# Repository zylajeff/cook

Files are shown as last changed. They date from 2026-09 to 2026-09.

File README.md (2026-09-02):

# Cook — Block-M Seeker

A Jetson Nano application that watches a Raspberry Pi camera feed for a
University of Michigan Block M, renders a missile-seeker HUD on the attached
display, and fires a pneumatic Nerf dart through a 12V solenoid — but only while
a physical toggle switch is held in the armed position.

```
camera ──▶ detector ──▶ tracker ──▶ interlocks ──▶ relay ──▶ solenoid
              │             │            │
              └─────────────┴────────────┴──────▶ seeker HUD ──▶ display
```

## Quick start

On a workstation with no hardware attached, everything runs against a synthetic
feed:

```bash
python -m pip install -e ".[dev]"
cook-vision --source synthetic --gpio mock --windowed
```

Press `a` to simulate flipping the arm switch, `f` to fire manually, `m` to see
the raw colour mask, `q` to quit.

On the Jetson:

```bash
python -m pip install -e ".[jetson]"     # NOT [dev]: keep the stock OpenCV
cook-vision
```

The camera source, GPIO backend, and display mode all default to `auto`, so the
bare command picks the CSI camera, real GPIO, and a fullscreen window.

## Safety

Firing is gated by eight interlocks, evaluated every frame and drawn along the
bottom of the HUD. All eight must pass:

| Interlock | Meaning |
|---|---|
| `startup` | 3s power-on lockout has elapsed |
| `arm switch` | the physical toggle is closed |
| `software safe` | the on-screen safety (`s`) is off |
| `target lock` | a track has persisted for 8 consecutive frames |
| `confidence` | the locked target scores ≥ 0.60 |
| `on bore` | the target is within 10% of frame width of the reticle |
| `cooldown` | ≥ 1.5s since the last shot |
| `relay idle` | the coil is not currently energised |

Three further protections are not interlocks but always apply:

- The relay pin is initialised to its **inactive** level, so bringing GPIO up
  cannot fire a dart.
- Every energise arms a watchdog timer that releases the coil after
  `max_pulse_seconds` (0.5s) even if the main loop stalls or crashes. A 12V
  solenoid held on will cook its coil.
- `atexit` and the shutdown path both de-energise the relay.

The launcher is fixed forward in this build — there is no pan/tilt yet — so the
`on bore` gate exists because a target the seeker can *see* is not necessarily a
target the barrel is *pointed at*.

## Detection

Two interchangeable backends behind one interface:

- **`color`** (default) — isolates the maize hue, then scores each blob against
  a rasterised Block-M template on four cues: `cv2.matchShapes` distance,
  bounding-box extent, convex-hull solidity, and aspect ratio. Needs no training
  data. On the synthetic bench a Block M scores ≈0.98 while a yellow disc scores
  ≈0.36 and a yellow square ≈0.26.
- **`onnx`** — a trained single-class YOLOv8 export. Drop it at
  `models/block-m.onnx` and run `cook-vision --model models/block-m.onnx`.

The colour backend is rotation-invariant by construction (Hu moments), which
also means an upside-down M reads as a match. If that matters, train the ONNX
model.

## Configuration

Every scalar in [`config.py`](src/cook_vision/config.py) is overridable as
`COOK_<SECTION>_<FIELD>`:

```bash
COOK_FIRING_PULSE_SECONDS=0.18 COOK_GPIO_RELAY_PIN=22 cook-vision
```

Useful ones: `COOK_DETECTOR_CONFIDENCE`, `COOK_DETECTOR_MAX_SHAPE_DISTANCE`,
`COOK_FIRING_AUTO_FIRE`, `COOK_FIRING_BORE_TOLERANCE`, `COOK_CAMERA_FLIP_METHOD`.

## Sound

Every shot plays `assets/sounds/trouble_with_the_snap.mp3` — the ABC/ESPN call
of Blake O'Neill's muffed punt snap, MSU 2015 — on a daemon thread, so a slow
or missing player never touches the frame budget. Needs one of `mpg123`
(preferred; decodes mp3 directly), `ffplay`, `cvlc`, or `aplay` on `PATH`:

```bash
sudo apt install mpg123
```

With none installed, sound silently disables itself (a warning is logged) and
the launcher still fires. `COOK_SOUND_ENABLED=false` turns it off deliberately.

Default output device is the Nano's HDMI audio (`plughw:0,3`) so a clip plays
through the display's speakers, not a jack nothing's plugged into. If the
display was off or asleep when the Nano booted, its HDMI audio jack-sense can
stay stuck `off` even though video works fine — reboot the Nano with the
display already on. Override the device with `COOK_SOUND_OUTPUT_DEVICE`
(find the right `card,device` with `aplay -l`).

## Wiring

See [docs/wiring.md](docs/wiring.md). Short version: relay signal on pin 18,
arm switch on pin 16 to ground, and **the solenoid's 12V supply must not come
from the Jetson**.

## Parts

See [docs/parts.md](docs/parts.md) for the full list with sourcing links —
compute/camera/display, the firing circuit, the pneumatic barrel adapter, and
the printed enclosure.

## Tests

```bash
python -m pytest
```

54 tests covering detector discrimination, track lifecycle, every interlock, the
relay watchdog, switch debouncing, and an end-to-end run on the synthetic feed.

## Not yet built

Pan/tilt. The Lynxmotion kit is deliberately out of scope for round one; the
`on bore` interlock is the seam where it will attach.

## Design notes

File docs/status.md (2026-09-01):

# Bring-up status

Last updated: 28 Aug 2026.

## Done

- [x] Full pipeline: capture → detect → track → interlocks → HUD, 65 tests passing
- [x] Backported to Python 3.6 for JetPack 4.2
- [x] OpenCV 3.3.1 compatibility (`cvcompat.py`)
- [x] Deployed to `burninator@192.168.86.30`, runs from source
- [x] `doctor` pre-flight green except DISPLAY
- [x] CSI camera confirmed working — GStreamer 1.14.1 linked into OpenCV
- [x] GPIO permissions fixed (gpio group + NVIDIA's udev rule)
- [x] Performance: 3 → 29 fps, now camera-limited
- [x] HUD verified on the 1024×600 panel
- [x] Chroma backend (`R − B` instead of HSV) implemented as
  `ChromaShapeDetector` / `COOK_DETECTOR_BACKEND=chroma`, subclassing the color
  backend's shape-scoring so only the mask differs. Tests cover the dim/warm
  maize and blue conditions that broke HSV. Known trade-off: R-B alone can't
  distinguish maize from generic red the way hue could — shape scoring is the
  only gate against that decoy now (see chroma.py).
- [x] Tried, then reverted, the tighter `maize_lower`/`maize_upper`
  `(18,172,160)-(32,255,255)` that a crop analysis suggested two nights ago
  but never actually got written to `config.py`. It appeared to break live
  detection of a Block M shown on a phone screen, but turned out **not** to
  be the tightened threshold — turning off some background light fixed
  detection with the reverted (old, looser) default still in place. Real
  cause was ambient light competing with the phone screen, not the HSV range.
  Current default `(18,120,120)-(34,255,255)` is unchanged; the tighter,
  crop-measured range was never actually at fault and is worth retrying later
  with a real `calibrate.py` reading rather than assumption either way.
- **New failure mode, distinct from the dim-target one below:** too much
  *competing* ambient light can wash out a self-lit source (phone screen)
  even though the target itself is well within threshold. Opposite direction
  from the original blocker (a dim, under-lit printed target). Both are real;
  don't let a fix for one be assumed to cover the other.
- [x] **Arm switch verified on real hardware.** `SAFE`/`ARMED` toggles cleanly,
  confirmed both on the raw GPIO probe and the HUD, solenoid still
  disconnected. Root cause of the long-running flakiness: pin 16 (and 15,
  which was tried and ruled out as pin-specific) has an internal pull-*down*
  baked in at the hardware/pinmux level that `Jetson.GPIO` can't disable,
  strong enough that a 10kΩ external pull-up only reached ~1V open-circuit —
  below the HIGH threshold — instead of 3.3V. **1kΩ**, not 10kΩ, is what
  actually overpowers it; `docs/wiring.md` now says so.

## Blocked

**Detection on the real target, not yet re-verified on hardware.** A printed
paper Block M produced a black mask on the camera — it reported the maize as
dim brown (`B 73 G 88 R 113`, brightness 113/255) and HSV thresholding failed
completely in that regime. The chroma backend above is the fix for that, built
and unit-tested against the measured colour values, but **not yet run against
the real camera** — next session should point the Nano at the actual target
with `COOK_DETECTOR_BACKEND=chroma` and confirm.

Ran both backends offline over the 258 `__train/block_m` / 314 `not_block_m`
photos (`/mnt/d/model_data/__train/`) as a sanity check: recall was a wash
(color 38.8%, chroma 37.6%) and chroma's false-positive rate was worse (33.1%
vs 20.7%), matching its documented can't-tell-red-from-maize trade-off. Not
read as a verdict — that corpus is general Block-M photos (logos, jerseys,
screenshots, per the dataset-defect audit in CLAUDE.md), not shots of the actual printed
target under real lighting, so it doesn't exercise the dim/warm case chroma
targets. The on-hardware test above is still the real answer.

If chroma doesn't fully resolve it: **trained YOLOv8n** is the fallback. Weights
already exist but need a JetPack 4.6 reflash plus a TensorRT engine — OpenCV
3.3.1 has no ONNX, and 4.1.1 predates reliable YOLOv8 ONNX support. Clean the
dataset and retrain first; see CLAUDE.md.

Also unresolved: whether the camera is simply underexposed. Worth ruling out
regardless, because a dim image still costs contrast under chroma too.

## Not started

- **The rest of the firing chain.** Arm switch is now verified (above); relay
  and solenoid are still untested — every run so far used a disconnected
  solenoid or `--gpio mock`. Next step is the relay with the solenoid still
  **disconnected**, listening for the click, then the solenoid itself.
- Pan/tilt (deliberately out of scope for round one).
- systemd service for start-on-boot.

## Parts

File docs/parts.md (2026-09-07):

# Parts list

Everything needed to build one rig. Links are the original sourcing links
(cleaned of tracking params); price/availability will drift, treat them as
"this is the part" rather than "buy from exactly here."

## Compute, camera, display

| Part | Spec | Source |
|---|---|---|
| Jetson Nano | B01 devkit carrier board | (already on hand — not sourced from a link) |
| Camera | Raspberry Pi CSI camera module | any CSI camera compatible with the Nano's connector; not spec'd beyond that |
| Display | Hosyond 7" IPS touchscreen, 1024×600, HDMI + USB-C | [amazon.com/dp/B0BKGCB18T](https://www.amazon.com/dp/B0BKGCB18T) |

## Firing circuit

| Part | Spec | Source |
|---|---|---|
| Solenoid valve | U.S. Solid, 1/8" NPT, 12V DC, 2-way normally closed | [amazon.com/dp/B06WLMX88B](https://www.amazon.com/dp/B06WLMX88B) |
| Relay module | ANMBEST 1-channel opto-isolated, 12V coil, high/low trigger select | [amazon.com/dp/B08PNHHC65](https://www.amazon.com/dp/B08PNHHC65) |
| Solenoid/relay battery pack | Aobao 8×AA holder, 12V, built-in ON/OFF switch and leads (sold as a 3-pack) | [amazon.com/dp/B09L7R2159](https://www.amazon.com/dp/B09L7R2159) |
| Arm switch | RobotShop RB-Spa-709, illuminated toggle with missile cover, 12V 20A contacts | [robotshop.com/products/illuminated-toggle-switch-red](https://www.robotshop.com/products/illuminated-toggle-switch-red) — RobotShop's own page doesn't give a pinout; see [wiring.md](wiring.md#the-arm-switch) for the terminal ID Jeff worked out with a multimeter |

Small electronics to have on hand, no specific vendor — any electronics
supplier: **1kΩ resistor** (arm-switch pull-up — see
[wiring.md](wiring.md#the-arm-switch) for why 1kΩ and not the more usual
10kΩ), **1N4007 flyback diode** (across the solenoid coil, if the relay board
doesn't already have one), **1-2A inline fuse** (12V rail), two small
screw-terminal distribution blocks (fan out the battery pack's + and − to the
relay and solenoid).

## Pneumatics — barrel adapter

Steps the solenoid's 1/8" NPT outlet up to a 1/2" PVC barrel. No specific
vendor — generic plumbing/hardware store parts (see
[wiring.md](wiring.md#the-barrel) for the assembly order):

- 1/8" NPT male-male nipple
- Reducer bushing, 1/2" NPT male × 1/8" NPT female
- PVC adapter, 1/2" Schedule 40, female adapter, slip × FPT
- 1/2" Schedule 40 PVC pipe, cut to barrel length
- PTFE tape (NPT joints) and PVC cement (the slip joint — not a dry press-fit)

## Enclosure

Printed, not purchased — see [hardware/enclosure.scad](../hardware/enclosure.scad).
One constant-depth box (display/switch/camera face, all four walls, CO2
hopper mounted on the right side wall) plus a thin back panel that slides
into channel grooves in the box's own left/right walls — carries the
Nano/battery/protoboard, pulls out for service. No fasteners, no flexing
parts, so PLA is a reasonable option here; PETG/ASA still resists warping
better on the panel's flat unsupported span.

## Not used in round one

| Part | Spec | Source |
|---|---|---|
| Pan/tilt kit | Lynxmotion aluminium pan and tilt kit | [robotshop.com/products/lynxmotion-pan-and-tilt-kit-aluminium2](https://www.robotshop.com/products/lynxmotion-pan-and-tilt-kit-aluminium2) |

Bought at project start, deliberately shelved — see "Not yet built" in
[README.md](../README.md). The `on bore` interlock is the seam it will
eventually attach to.

## Provenance

The Amazon/RobotShop links above trace back to the project's original
planning note (outside this repo, in Jeff's Obsidian vault) — this file is
that note's hardware list, reconciled with what `docs/wiring.md` has since
confirmed against the physical parts (part numbers, pinouts, the exact
resistor value) as the build actually came together.

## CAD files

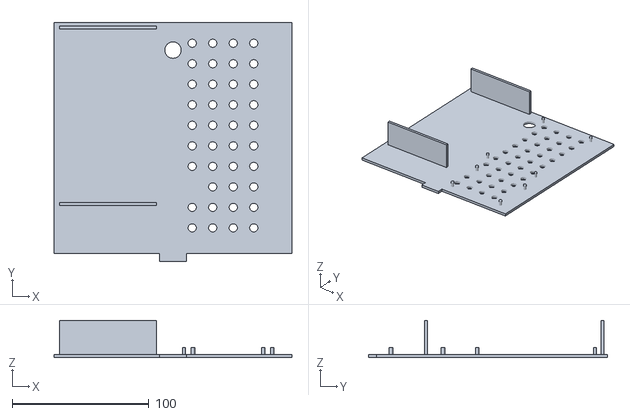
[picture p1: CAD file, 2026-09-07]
hardware/rear_shell.stl
174.0 x 174.4 x 27.4

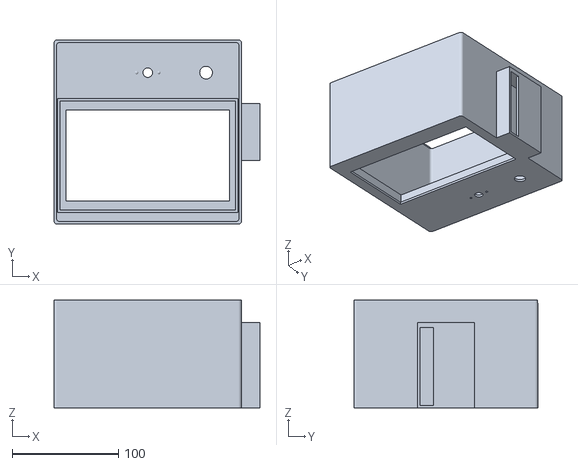
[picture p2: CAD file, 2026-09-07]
hardware/front_shell.stl
194.3 x 173.8 x 101.6

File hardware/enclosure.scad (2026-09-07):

// ============================================================
// COOK rig enclosure v3 — single constant-depth box, fastener-free:
// no screws, inserts, nuts, or glue anywhere. The telescoping
// two-shell design (v2) is gone. Now it's ONE printed box (front
// face + all four side walls, open at the back) plus a THIN back
// panel that slides down into channel grooves cut into the box's
// own left/right inner walls — closes the box, and pulls back out
// for service. The CO2 hopper moved off the back (there's no back
// wall to hang it on anymore) onto the right side wall instead.
//
// Open in OpenSCAD (openscad.org). PLACEHOLDER dimensions below are
// marked "MEASURE YOURS" — confirm against your actual parts, then
// F5 (preview) before F6 (render) / STL export.
//
// Print each part as a SEPARATE STL: set exactly one render_* flag
// true, F6, export, repeat. render_assembly shows both together for
// a fit-check only.
//
// Material: PETG or ASA. Nothing flexes/snaps anymore (no collar,
// no snap bump) — the panel is a plain slide-and-friction fit — so
// PLA is a more reasonable option here than it was for v2, though
// PETG/ASA still resists warping on that big flat panel better.
//
// AXIS CONVENTION: X = box width (face_w), Y = box height (face_h),
// Z = box depth, front face in the XY plane at Z=0. Unlike v2, this
// is now the ONLY frame in the file — box_shell() and back_panel()
// are both authored directly in it, so render_assembly doesn't need
// to translate anything to line them up. That was a real source of
// error last time (the collar math needed careful by-hand
// re-derivation); removing the second local frame removes that
// whole class of mistake.
//
// I still do not have OpenSCAD running in the environment this was
// written in — everything below is worked out from the numbers, not
// rendered. Spots flagged "FLAG:" are the ones most likely to need a
// nudge once you actually preview it.
// ============================================================

// ---- WHICH PART TO RENDER ----
render_box      = false;
render_panel    = false;
render_assembly = true;

// ---- GLOBAL TOLERANCES ----
wall      = 2.4;   // shell wall thickness (~6 perimeters at 0.4mm nozzle)
fit_gap   = 0.25;  // clearance budget for the panel's slide fit
corner_r  = 3;     // outer corner rounding
$fn       = 48;

// ============================================================
// MEASURE-AND-CONFIRM: component footprints
// Unchanged from v2 — confirmed from spec sheets: display, camera,
// battery pack, switch panel-hole diameter. Everything else is a
// reasonable placeholder — measure your actual part and edit before
// slicing.
// ============================================================

// -- Display: Hosyond 7", CONFIRMED from spec sheet --
disp_l = 164.9; disp_w = 102.0; disp_h = 15.15;
disp_active_l = 154.21; disp_active_w = 85.92;
disp_sleeve_clr = 0.8;  // total clearance around the display's outer edge in its retaining sleeve (0.4mm/side) -- looser than fit_gap (meant for small parts), since a slide-fit this size needs more margin for print tolerance; loosen further if it doesn't slide in easily

// -- Camera: Raspberry Pi Camera Module v2, CONFIRMED standard footprint --
cam_pcb_l = 25; cam_pcb_w = 24; cam_pcb_h = 9;
cam_hole_pitch = 21;   // the two M2 mounting holes, this far apart, centered on the board
cam_hole_d     = 2.4;  // clearance for an M2 self-tapper / heat-set insert-free press fit
cam_lens_d     = 9;    // front clearance hole for the lens barrel + ribbon strain relief

// -- Jetson Nano, MEASURED directly from NVIDIA's own STEP file for
//    the B01 dev kit (Jetson_Nano_Dev_Kit_3D_b01.stp, PRODUCT
//    '142-13449-1000-B01') by parsing its board-outline edges and
//    mounting-hole circles — not a datasheet guess, not the old
//    generic placeholder. Board outline: 100.0 x 79.0mm.
//
//    You said you actually have the original (A02) board, not B01 —
//    this file was the closest thing on hand. NVIDIA designed the
//    B01 carrier board to be mechanically drop-in compatible with
//    A02 specifically so existing cases wouldn't break, so the board
//    outline and hole pattern below should carry over — but I
//    couldn't confirm that against an A02 STEP file directly, so
//    it's still worth a quick check against your actual board before
//    slicing anything.
//
//    nano_h is the tallest point found anywhere within the board's
//    own footprint in that STEP file (i.e. heatsink included) — real
//    data, but specific to whatever heatsink ships with the B01 kit;
//    if your A02's heatsink/fan shroud is a different height, this
//    is the one number here still worth measuring directly. --
nano_l = 100; nano_w = 79; nano_h = 22;

// Mounting-hole offsets from the board's own center — MEASURED, and
// NOT symmetric (many boards aren't): 4mm/10mm inset from the
// left/right edges, 17mm/4mm inset from the bottom/top edges. Used
// directly by the Nano's peg placement in back_panel() instead of
// wall_snap_pegs()'s generic symmetric inset, which was wrong for
// this board specifically (it assumed a centered rectangle).
nano_hole_dx = [-46, 40];      // X offsets from nano_cx: left pair, right pair
nano_hole_dy = [-22.5, 35.5];  // Y offsets from nano_cy: bottom pair, top pair
nano_hole_r  = 1.38;           // measured clearance-hole radius (~2.76mm dia, M2.5 clearance)

// -- Aobao 8xAA battery holder, CONFIRMED from the listing:
//    12.6 x 7.1 x 2.0cm (L x W x H), 14cm leads each. --
batt_l = 126; batt_w = 71; batt_h = 20;
batt_lead_len = 140;

// -- Small protoboard you'll solder the relay/fuse/resistor circuit
//    to (PLACEHOLDER — size to whatever board you actually buy) --
pcb_l = 70; pcb_w = 50;
pcb_thickness = 15;  // PLACEHOLDER — rough guess for a populated board (relay, terminal blocks); measure yours

// -- Firing (arm) switch, SparkFun "Toggle Switch and Cover -
//    Illuminated (Red)". Panel hole CONFIRMED at 12mm from the
//    listing. Behind-panel depth is still not published anywhere —
//    PLACEHOLDER, measure the body + missile-cover mechanism with
//    calipers before slicing. --
switch_bushing_d = 12;  // CONFIRMED
switch_body_len  = 35;  // PLACEHOLDER — clearance needed behind the panel for the switch + lugs + missile cover mechanism

// -- 12g CO2 cartridge, typical published dims for a threaded 12g —
//    verify against your actual brand, some run longer. --
co2_d       = 12.6;  // clearance diameter (cartridge body + a hair)
co2_len     = 68;
co2_count   = 3;      // channels, stacked vertically — one cartridge each, lying flat

// ============================================================
// FRONT-FACE LAYOUT. Display centered vertically in its own zone;
// camera centered above it; switch shares the top row with the
// camera instead of sitting beside the display.
//
// box_w and box_h are each the larger of two independent floors: the
// front face's own needs, and the back panel's electronics layout
// (battery + cable gap + Nano/protoboard — see ELECTRONICS LAYOUT).
// Getting the printed footprint down to fit a 220mm bed (a friend's
// printer flagged the earlier version as ~25% too big) meant tuning
// BOTH floors together, not just one — margins alone couldn't get
// there (battery + Nano side by side need ~171mm before any margin
// at all), so the Nano is now mounted ROTATED 90° from its natural
// resting orientation: its narrower 79mm side sets the column width
// instead of its 100mm side, trading some width for extra height on
// the back panel (which had plenty of slack to give). Same reasoning
// as the battery's own rotation earlier in this file.
// ============================================================
side_margin    = 6;    // left/right edge margin — trimmed from 12; still clear of corner_r
cam_switch_gap = 15;   // gap between the camera zone and the switch zone (same row now)
cam_zone_w     = 40;   // width reserved for the camera mount
switch_zone_w  = 40;   // width reserved for the switch mount

top_margin    = 12;
cam_zone_h    = 34;   // height reserved for the camera/switch row
cam_gap       = 10;   // gap between that row and the display's top edge
bottom_margin = 12;

// Used here for the electronics floors AND in ELECTRONICS LAYOUT
// below (battery/Nano/protoboard column positioning) — one
// definition, so the two can't drift apart.
component_margin = 3;   // horizontal clearance from each column to the interior wall — thin, this is the tightest margin in the file besides the cable hole itself
vmargin           = 5;   // vertical clearance within a column (floor/ceiling)
stack_gap         = 9;   // gap between the Nano and the protoboard stacked above it
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

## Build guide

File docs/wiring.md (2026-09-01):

# Wiring

Pin numbers are **BOARD** numbering on the Jetson Nano 40-pin header (physical
position), which is what `Jetson.GPIO` is configured for in
[`hardware.py`](../src/cook_vision/hardware.py).

## Defaults

| Signal | Pin | Notes |
|---|---|---|
| Relay IN1 | 18 | `COOK_GPIO_RELAY_PIN` — logic signal only |
| Relay DC+/DC- | — | **12V, from the same battery pack as the solenoid — not the Jetson.** The relay is a Songle SRD-12VDC-SL-C, a 12V-coil part; the board's own datasheet/silkscreen confirms it. Jetson only supplies IN1. |
| Jetson GND | any GND pin | Tie to the 12V pack's negative terminal — IN1's optocoupler needs a shared ground reference with DC-, same as the solenoid's ground-sharing requirement below. |
| Arm switch | 16 | `COOK_GPIO_ARM_SWITCH_PIN`, **needs an external 1kΩ pull-up to 3.3V** (pin 1 or 17) — see "The arm switch" below |
| Arm switch return | 14 | GND |

Relay terminal blocks, from the board itself:
- **`IN1` / `DC-` / `DC+`** (logic side) — `IN1` to Jetson pin 18. `DC+`/`DC-` to
  the 12V battery pack, **not** the Jetson header.
- **`NC` / `COM` / `NO`** (switched side) — `COM`/`NO` to the solenoid circuit
  per "The solenoid" below. `NC` unused.

There's also a small jumper on the board near a silkscreened `H` — likely the
active-high/active-low trigger select this module's "High/Low Level Trigger"
labeling refers to. Check its position/datasheet before relying on the
`relay_active_low` software default; if you can select the polarity in
hardware, make sure it agrees with the config rather than fighting it.

## Parts

- **Relay**: ANMBEST 1-channel opto-isolated relay module, 12V, high/low trigger.
- **Solenoid**: U.S. Solid 1/8" NPT electric solenoid valve, 12V DC, 2-way
  normally closed.
- **Display**: Hosyond 7" IPS touchscreen, 1024x600. HDMI video, powered over
  its own USB-C cable at 5V/0.62A (2.55W) — light enough to run off the
  Jetson's own USB port rather than a separate supply.
- **Camera**: Raspberry Pi CSI camera, connects to the Nano's CSI connector
  directly. No external power.
- **Arm switch**: RobotShop RB-Spa-709, illuminated toggle switch with missile
  cover, 12V 20A contacts, LED runs from as low as 3.3V. See "The arm switch"
  below — the lamp isn't wired up, so it draws nothing from any supply here.
  RobotShop's own datasheet has no pinout diagram, so confirm the switch-vs-LED
  terminals with a multimeter before wiring rather than trusting a labeled
  scheme — there isn't one.
- **Solenoid power**: Aobao 8×AA 12V battery holder, ON/OFF switch and leads
  built in (sold as a 3-pack — two spares).

(Sourced from the original planning note. PSI/orifice rating for the solenoid
wasn't captured there — read it off the valve body or its listing if a
firing-pressure calculation needs it.)

## Power plan

**One wall outlet, no custom mains wiring**, plus a battery pack that needs
none at all:

1. **Jetson's own 5V supply** (barrel jack, 5V/4A) — the only thing actually
   plugged into the wall. Powers the Nano, and the display piggybacks on it
   over USB, so no separate brick for the screen. The Jetson supplies nothing
   else — the relay's coil is a 12V part (see "Defaults" above), not 5V, so
   it can't be powered from the Jetson's own header either.
2. **The 12V rail runs on batteries**, not mains: the Aobao 8×AA holder above,
   in place of a wall adapter, powering *both* the solenoid coil and the
   relay's DC+/DC- terminals. Its built-in ON/OFF switch doubles as a
   physical kill switch on the whole firing circuit, independent of the arm
   toggle. Use alkaline cells, not rechargeable NiMH — 8 NiMH cells only give
   9.6V nominal, which under-drives both 12V-rated parts and risks weak or
   unreliable actuation.

Kept on two entirely separate supplies deliberately, mains or not: the
solenoid is an inductive load that puts a switching spike on whatever rail it
shares, and you don't want that landing on the Jetson's compute rail mid-frame.
Add an inline fuse (1-2A) between the battery pack and the relay board — it's
now covering both the relay coil and the solenoid coil, and a bare battery
pack has no overcurrent protection of its own the way a wall adapter would.

## The relay

The common blue opto-isolated relay boards are **active-low**: the coil pulls in
when IN is driven LOW. That is the default (`relay_active_low: True`). If your
board energises on HIGH instead, set `COOK_GPIO_RELAY_ACTIVE_LOW=0` — otherwise
the logic is inverted and the solenoid will sit energised at idle.

Confirm before connecting the solenoid:

```bash
PYTHONPATH=src python3 -c "
from cook_vision.config import GpioConfig
from cook_vision.hardware import SolenoidRelay, build_backend
r = SolenoidRelay(build_backend(), GpioConfig(), 0.5)
input('Relay should be OFF. Enter to pulse...'); r.pulse(0.3)
"
```

You should hear one click in, one click out. If it clicks in as soon as the
script starts, your `active_low` setting is wrong.

## The solenoid

**Do not power the 12V solenoid from the Jetson.** It draws far more than the
carrier board can supply, and the inductive kickback on release will find its
way into your GPIO. Use a separate 12V supply:

```
12V+ ──── solenoid ──── relay COM
                        relay NO ──── 12V−
```

Put a flyback diode (1N4007, cathode to 12V+) across the solenoid coil if the
relay board does not already have one. Tie the 12V supply ground to the Jetson
ground so the two share a reference.

### Feeding the relay and the solenoid from one battery pack

The relay's DC+/DC- and the solenoid circuit are separate loads sharing the
same 12V pack, not wired in series — each battery terminal fans out to more
than one destination:

```
                    ┌── fuse (1-2A) ──┬── relay DC+
battery 12V+ ───────┘                 └── solenoid (one lead)

solenoid (other lead) ──── relay COM

                    ┌── relay DC-
battery 12V− ───────┼── relay NO
                    └── Jetson GND
```

Do the fan-out with a small screw-terminal distribution block per rail (one
in, several out) rather than twisting/soldering bare leads together — cheap,
and easy to redo if you rewire later. Fuse goes on the **positive** lead,
between the battery and the distribution block, so it protects the whole 12V
rail (relay coil + solenoid coil) with one part.

Cheap inline fuse holders often ship as a single continuous loop of wire
threaded through both ends of the holder body, rather than two separate
leads — cut the loop once, at the point opposite the housing, to get the
"from battery" and "to distribution block" leads shown above.

Fuse color (standard blade-style ATO/ATC/Mini code — glass 3AG/AGC fuses
aren't reliably color-coded the same way, so read the rating printed on the
fuse itself if the holder takes one of those instead):

| Rating | Color |
|---|---|
| 1A | Black |
| 2A | Gray |

### The barrel

The solenoid's air outlet is 1/8" NPT — much smaller than a 1/2" PVC barrel
sized for a Nerf dart, so it takes two fittings to step up. Permanent joint,
not swappable (a quick-connect coupler/plug pair would go here instead if
that changes):

```
solenoid outlet ── 1/8" NPT male-male nipple ── reducer bushing ── PVC female adapter ── PVC barrel
                    (already have)               1/2" NPT male ×    1/2" FPT × slip,     glued in
                                                  1/8" NPT female    threads onto bushing
```

- Reducer bushing: 1/2" NPT male × 1/8" NPT female.
- PVC adapter: 1/2" Schedule 40, female adapter, slip × FPT.

PTFE tape on both NPT joints (tapered thread, needs it to seal). Actual PVC
cement on the slip joint, not a dry press-fit — that joint holds the
regulator's pressure at the moment of firing, and an unglued PVC fitting can
pop off under a pressure pulse rather than just leak.

## The arm switch

RobotShop RB-Spa-709. **Three** posts, marked `+`, `LED`, and `ground`
(RobotShop's own sheet has no pinout diagram — this is read off the part
itself, plus a multimeter check). The switch's actual contacts are `+` and
`LED` — on this design the LED taps its power off the same post the switch
switches, it isn't a separate isolated circuit. Confirmed by testing: `+` and
`LED` showed continuity in both probe directions (rules out one of them
secretly being a diode/LED leg) and toggled open/closed with the lever (rules
out a fixed internal tie). `ground` is the LED's cathode only, untouched by
the switch action.

- **`+` and `LED`** — the switch. One to Jetson pin 16, the other to ground
  (pin 14) — it's a plain non-polarized contact, doesn't matter which post
  goes to which pin.
- **`ground`** — leave disconnected. It's the LED's return path, not Jetson
  ground, and not part of the switch action.
- If the lamp ever gets wired up later: `+`/`LED` would then be carrying
  whatever powers the lamp, so it can't also go straight to a 3.3V GPIO pin —
  same shared-node caveat this doc had originally, before an in-between draft
  briefly (and wrongly) called this a 4-terminal, fully-isolated part.

**Needs an external pull-up.** `Jetson.GPIO` on this JetPack version silently
ignores `setup()`'s `pull_up_down` argument (it'll even print
`UserWarning: Jetson.GPIO ignores setup()'s pull_up_down parameter` if you're
watching for it) — the internal pull-up the software asks for never actually
gets applied, so pin 16 is left floating when the switch is open rather than
held HIGH. Symptom: wiring and software both look correct, but arming doesn't
reliably toggle.

That's only half the story, though: a first attempt at a 10kΩ external
pull-up **still** didn't fix it. Root cause, confirmed on real hardware: pin
16 (and pin 15, tried as an alternative and ruled out — this isn't specific
to pin 16) has an internal pull-*down* baked in at the hardware/pinmux level
that `Jetson.GPIO` cannot disable. It's strong enough that a 10kΩ external
pull-up only reached about 1V open-circuit — below the HIGH threshold —
instead of the 3.3V it should read. **1kΩ**, not 10kΩ, is what actually
overpowers the internal pull-down. Fix is a real external pull-up: **1kΩ
resistor from pin 16 to a 3.3V pin (pin 1 or 17)**. With that in place, the
software's `arm_switch_active_low: True` default and the fail-safe "broken
wire reads SAFE" behavior work as originally intended — it's the internal
pull-up specifically that doesn't exist here, not the pull-up concept
itself, and the pull-down means the resistor also has to be stronger than
the 10kΩ a plain floating-pin fix would normally call for.

Debouncing is handled in software (50ms); no RC network needed.

### Probing the raw pin

`ArmSwitch` only logs when its *debounced* state changes, which hides
whether the raw pin is actually toggling at all. To watch the raw GPIO level
directly, bypassing debounce and the rest of the app entirely:

```bash
PYTHONPATH=src python3 -c "
import time
from cook_vision.config import GpioConfig
from cook_vision.hardware import build_backend

config = GpioConfig()
backend = build_backend('jetson')  # 'jetson' not 'auto': fail loudly if it falls back to mock
backend.setup_input(config.arm_switch_pin, pull_up=config.arm_switch_active_low)
print('Watching pin', config.arm_switch_pin, '- Ctrl+C to stop')
last = None
while True:
    level = backend.read(config.arm_switch_pin)
    if level != last:
        print(time.strftime('%H:%M:%S'), 'raw level =', level)
        last = level
    time.sleep(0.1)
"
```

Toggle the switch while this runs. If nothing prints, the raw pin genuinely
never changes — the fault is upstream in the wiring (switch, pull-up, or the
header connection), not in the software's debounce or active-low logic. If it
does print both levels correctly, the hardware path is fine and the bug is in
how the app interprets or displays that state instead.

## The display and camera

Two cables each, both to the Jetson, no external power:

- **Display** — HDMI (video) + USB-C (power + touch) into any Jetson USB port.
- **Camera** — CSI ribbon cable into the Nano's camera connector.

Neither needs anything from the 12V rail or the power plan above beyond the
Jetson's own 5V supply already covering them.

## First power-on checklist

0. Both supplies connected (Jetson 5V, solenoid 12V), solenoid and switch
   wired per above.
1. Solenoid **disconnected**. Run `cook-vision` and confirm the HUD shows `SAFE`.
2. Flip the toggle. The HUD should switch to a blinking red `ARMED` and the
   `ARM SWITCH` interlock dot should turn green.
3. Still disconnected, hold a Block M in front of the camera at centre frame.
   You should hear the relay click. If it does not, read the interlock row — it
   names exactly which gate is holding.
4. Only then connect the solenoid, and point it somewhere safe.

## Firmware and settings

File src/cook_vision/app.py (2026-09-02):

"""Application entry point: capture -> detect -> track -> interlock -> display."""
import argparse
import logging
import signal
import sys
import time
from collections import deque

import cv2

from .camera import Camera
from .config import Config
from .detectors import build_detector
from .firing import FireController
from .hardware import ArmSwitch, MockGpioBackend, SolenoidRelay, build_backend
from .hud import SeekerHud
from .sound import build_soundboard
from .tracker import TargetTracker

LOGGER = logging.getLogger("cook")

HELP = """keys:  q/ESC quit   s software safety   f manual fire
       a toggle mock arm switch   m mask view   w windowed/fullscreen"""


def fit_to_display(frame, display):
    """Resize once, up front, so everything downstream shares one coordinate space.

    Drawing the HUD at the panel's native size is cheaper than drawing it large
    and letting the window scale it, and it keeps the text crisp instead of
    resampled. Detection, tracking, and the bore check then all agree on what
    "frame width" means.
    """
    if not display.width or not display.height:
        return frame
    height, width = frame.shape[:2]
    if (width, height) == (display.width, display.height):
        return frame
    # On CSI this is a no-op: the ISP already delivered the display size. It
    # only runs for V4L2, file, and synthetic sources. INTER_LINEAR throughout,
    # for the reason documented in DownscaledDetector._shrink.
    return cv2.resize(frame, (display.width, display.height),
                      interpolation=cv2.INTER_LINEAR)


class SeekerApp:
    def __init__(self, config: Config):
        self.config = config
        self.camera = Camera(config.camera)
        self.detector = build_detector(config.detector)
        self.tracker = TargetTracker(config.tracker)

        self.gpio = build_backend(config.gpio.backend)
        self.arm_switch = ArmSwitch(self.gpio, config.gpio)
        self.relay = SolenoidRelay(self.gpio, config.gpio, config.firing.max_pulse_seconds)
        self.controller = FireController(self.relay, self.arm_switch, config.firing)

        self.sound = build_soundboard(config.sound)
        self.hud = SeekerHud(config.display, config.firing)
        self._frame_times = deque(maxlen=30)
        self._show_mask = False
        self._running = True
        self._window_open = False

    # -- lifecycle -----------------------------------------------------------

    def _open_window(self):
        if self.config.display.headless or self._window_open:
            return
        name = self.config.display.window_name
        cv2.namedWindow(name, cv2.WINDOW_NORMAL)
        if self.config.display.fullscreen:
            cv2.setWindowProperty(name, cv2.WND_PROP_FULLSCREEN, cv2.WINDOW_FULLSCREEN)
        self._window_open = True

    def stop(self, *_):
        self._running = False

    def shutdown(self):
        """Make the rig safe, then release everything. Safe to call twice."""
        self.controller.safe()
        self.camera.release()
        self.detector.close()
        try:
            self.gpio.cleanup()
        except Exception as error:
            LOGGER.warning("GPIO cleanup failed: %s", error)
        if self._window_open:
            cv2.destroyAllWindows()
        LOGGER.info("Shutdown complete. %d shot(s) fired.", self.controller.shots)

    # -- input ---------------------------------------------------------------

    def _handle_key(self, key):
        if key in (ord("q"), 27):
            self.stop()
        elif key == ord("s"):
            self.controller.toggle_software_safe()
        elif key == ord("f"):
            self.controller.request_fire()
        elif key == ord("m"):
            self._show_mask = not self._show_mask
        elif key == ord("w"):
            self.config.display.fullscreen = not self.config.display.fullscreen
            cv2.setWindowProperty(
                self.config.display.window_name,
                cv2.WND_PROP_FULLSCREEN,
                cv2.WINDOW_FULLSCREEN if self.config.display.fullscreen else cv2.WINDOW_NORMAL,
            )
        elif key == ord("a") and isinstance(self.gpio, MockGpioBackend):
            # Development only: simulate the operator flipping the toggle switch.
            pin = self.config.gpio.arm_switch_pin
            level = 0 if self.gpio.read(pin) else 1
            self.gpio.set_input_level(pin, level)

    def _fps(self):
        if len(self._frame_times) < 2:
            return 0.0
        span = self._frame_times[-1] - self._frame_times[0]
        return (len(self._frame_times) - 1) / span if span > 0 else 0.0

    # -- main loop -----------------------------------------------------------

    def run(self) -> int:
        LOGGER.info("Camera: %s", self.camera.description)
        LOGGER.info("Detector: %s | GPIO: %s", self.detector.name, self.gpio.name)
        LOGGER.info("Firing lockout for %.1fs", self.config.firing.startup_lockout_seconds)
        print(HELP)

        self._open_window()
        shots_before = self.controller.shots

        while self._running:
            ok, frame = self.camera.read()
            if not ok or frame is None:
                LOGGER.error("Camera read failed; stopping.")
                return 1

            frame = fit_to_display(frame, self.config.display)
            self._frame_times.append(time.monotonic())
            self.arm_switch.update()

            detections = self.detector.detect(frame)
            self.tracker.update(detections, frame.shape)
            decision = self.controller.update(self.tracker, frame.shape)

            if self.controller.shots != shots_before:
                self.hud.flash()
                self.sound.play_fire()
                shots_before = self.controller.shots

            if self.config.display.headless:
                continue

            if self._show_mask and hasattr(self.detector, "mask"):
                frame = cv2.cvtColor(self.detector.mask(frame), cv2.COLOR_GRAY2BGR)

            telemetry = {
                "fps": self._fps(),
                "backend": self.detector.name,
                "source": self.camera.source if hasattr(self.camera, "source") else "synthetic",
                "shots": self.controller.shots,
            }
            frame = self.hud.render(frame, self.tracker, decision, self.controller, telemetry)
            cv2.imshow(self.config.display.window_name, frame)
            self._handle_key(cv2.waitKey(1) & 0xFF)

        return 0


def build_parser():
    parser = argparse.ArgumentParser(
        prog="cook-vision",
        description="Block-M seeker and pneumatic dart launcher control.",
    )
    parser.add_argument("--source", choices=["auto", "csi", "v4l2", "file", "synthetic"])
    parser.add_argument("--device", help="camera index, or a path for --source file")
    parser.add_argument("--detector", choices=["color", "chroma", "onnx"])
    parser.add_argument("--model", help="path to the ONNX model")
    parser.add_argument("--confidence", type=float)
    parser.add_argument("--width", type=int)
    parser.add_argument("--height", type=int)
    parser.add_argument("--no-auto-fire", action="store_true",
                        help="require the f key even when every interlock passes")
    parser.add_argument("--windowed", action="store_true")
    parser.add_argument("--headless", action="store_true",
                        help="run the pipeline with no display; for soak testing")
    parser.add_argument("--gpio", choices=["auto", "jetson", "mock"])
    parser.add_argument("--verbose", "-v", action="store_true")
    return parser


def apply_args(config: Config, args) -> Config:
    if args.source:
        config.camera.source = args.source
    if args.device:
        config.camera.device = args.device
    if args.width:
        config.camera.width = args.width
    if args.height:
        config.camera.height = args.height
    if args.detector:
        config.detector.backend = args.detector
    if args.model:
        config.detector.model_path = args.model
        config.detector.backend = "onnx"
    if args.confidence is not None:
        config.detector.confidence = args.confidence
    if args.no_auto_fire:
        config.firing.auto_fire = False
    if args.windowed:
        config.display.fullscreen = False
    if args.headless:
        config.display.headless = True
    if args.gpio:
        config.gpio.backend = args.gpio
    return config


def main(argv=None) -> int:
    args = build_parser().parse_args(argv)
    logging.basicConfig(
        level=logging.DEBUG if args.verbose else logging.INFO,
        format="%(asctime)s %(levelname)-7s %(name)s: %(message)s",
        datefmt="%H:%M:%S",
    )

    config = apply_args(Config.from_env(), args)
    LOGGER.debug("Configuration:\n%s", config.describe())

    app = SeekerApp(config)
    signal.signal(signal.SIGINT, app.stop)
    signal.signal(signal.SIGTERM, app.stop)
    try:
        return app.run()
    finally:
        app.shutdown()


if __name__ == "__main__":
    sys.exit(main())

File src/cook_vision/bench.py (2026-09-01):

"""Per-stage timing, to find where the frame budget actually goes.

    python3 -m cook_vision.bench                     # synthetic feed
    python3 -m cook_vision.bench --source csi        # real camera
    python3 -m cook_vision.bench --source csi --show # include the imshow cost

Reports the median millisecond cost of each stage. The median rather than the
mean because the first few frames include one-off allocations.
"""

import argparse
import sys
import time

import cv2

from .app import fit_to_display
from .camera import Camera
from .config import Config
from .detectors import build_detector
from .firing import FireController
from .hardware import ArmSwitch, SolenoidRelay, build_backend
from .hud import SeekerHud
from .tracker import TargetTracker


def _median(values):
    ordered = sorted(values)
    middle = len(ordered) // 2
    if not ordered:
        return 0.0
    if len(ordered) % 2:
        return ordered[middle]
    return (ordered[middle - 1] + ordered[middle]) / 2.0


def _time(label, fn, repeats=25):
    fn()
    start = time.time()
    for _ in range(repeats):
        result = fn()
    print("    {0:<20} {1:7.2f} ms".format(label, (time.time() - start) / repeats * 1000))
    return result


def _deep(camera, detector, config):
    """Break the detector down on a real frame from this camera."""
    from .cvcompat import find_contours

    ok, frame = camera.read()
    if not ok:
        return
    inner = getattr(detector, "inner", detector)
    width = getattr(detector, "width", 0)

    print("-" * 46)
    print("  detector breakdown (frame {0}x{1})".format(frame.shape[1], frame.shape[0]))
    if width and frame.shape[1] > width:
        scaled = _time("resize to %d" % width, lambda: detector._shrink(
            frame, width / float(frame.shape[1])))
    else:
        scaled = frame
        print("    {0:<20} {1:>7}".format("resize", "skipped"))

    source = scaled
    if inner.config.blur:
        source = _time("GaussianBlur", lambda: cv2.GaussianBlur(scaled, (5, 5), 0))
    hsv = _time("cvtColor BGR2HSV", lambda: cv2.cvtColor(source, cv2.COLOR_BGR2HSV))
    _time("inRange maize", lambda: cv2.inRange(hsv, inner.maize_lower, inner.maize_upper))
    _time("inRange blue", lambda: cv2.inRange(hsv, inner.blue_lower, inner.blue_upper))
    mask = _time("mask (whole stage)", lambda: inner.mask(scaled))
    contours = _time("findContours", lambda: find_contours(mask))
    _time("scoring loop", lambda: [inner.score(c) for c in contours])
    print("    {0:<20} {1:7d}".format("contours", len(contours)))
    if contours:
        areas = sorted(cv2.contourArea(c) for c in contours)
        print("    {0:<20} min {1:.0f}  max {2:.0f}  (min_area_px {3})".format(
            "contour areas", areas[0], areas[-1], inner.config.min_area_px))
        best = max(inner.score(c) for c in contours)
        print("    {0:<20} {1:7.3f}".format("best score", best))


def main(argv=None):
    parser = argparse.ArgumentParser(description="Time each pipeline stage")
    parser.add_argument("--source", default="synthetic")
    parser.add_argument("--frames", type=int, default=40)
    parser.add_argument("--width", type=int)
    parser.add_argument("--height", type=int)
    parser.add_argument("--show", action="store_true", help="include imshow in the timings")
    parser.add_argument("--deep", action="store_true",
                        help="also break the detector down stage by stage")
    args = parser.parse_args(argv)

    config = Config.from_env()
    config.camera.source = args.source
    if args.width:
        config.camera.width = args.width
    if args.height:
        config.camera.height = args.height
    config.gpio.backend = "mock"

    camera = Camera(config.camera)
    detector = build_detector(config.detector)
    tracker = TargetTracker(config.tracker)
    gpio = build_backend("mock")
    controller = FireController(
        SolenoidRelay(gpio, config.gpio, config.firing.max_pulse_seconds),
        ArmSwitch(gpio, config.gpio),
        config.firing,
    )
    hud = SeekerHud(config.display, config.firing)

    if args.show:
        cv2.namedWindow("bench", cv2.WINDOW_NORMAL)

    stages = {"read": [], "fit": [], "detect": [], "track": [], "hud": [], "show": []}
    ok, frame = camera.read()
    if not ok:
        print("camera read failed", file=sys.stderr)
        return 1
    print("source: {0}  frame: {1}x{2}  frames: {3}".format(
        camera.description, frame.shape[1], frame.shape[0], args.frames))

    for _ in range(args.frames):
        t0 = time.time()
        ok, frame = camera.read()
        t1 = time.time()
        if not ok:
            break
        frame = fit_to_display(frame, config.display)
        t1b = time.time()
        detections = detector.detect(frame)
        t2 = time.time()
        tracker.update(detections, frame.shape)
        decision = controller.update(tracker, frame.shape)
        t3 = time.time()
        rendered = hud.render(frame, tracker, decision, controller,
                              {"fps": 0.0, "backend": detector.name,
                               "source": args.source, "shots": 0})
        t4 = time.time()
        if args.show:
            cv2.imshow("bench", rendered)
            cv2.waitKey(1)
        t5 = time.time()

        stages["read"].append((t1 - t0) * 1000)
        stages["fit"].append((t1b - t1) * 1000)
        stages["detect"].append((t2 - t1) * 1000)
        stages["track"].append((t3 - t2) * 1000)
        stages["hud"].append((t4 - t3) * 1000)
        stages["show"].append((t5 - t4) * 1000)

    if args.deep:
        _deep(camera, detector, config)

    camera.release()
    if args.show:
        cv2.destroyAllWindows()

    print("-" * 46)
    total = 0.0
    for name in ("read", "fit", "detect", "track", "hud", "show"):
        if not stages[name] or (name == "show" and not args.show):
            continue
        value = _median(stages[name])
        total += value
        print("  {0:<8} {1:7.1f} ms".format(name, value))
    print("-" * 46)
    print("  {0:<8} {1:7.1f} ms  ({2:.1f} fps)".format(
        "total", total, 1000.0 / total if total else 0.0))
    return 0


if __name__ == "__main__":
    sys.exit(main())

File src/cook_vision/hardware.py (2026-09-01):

"""GPIO: the arming switch input and the solenoid relay output.

Safety notes that drive the design here:

* The relay pin is configured with its **inactive** level as the initial value,
  so bringing the pin up as an output cannot glitch the solenoid.
* Every energise arms an independent watchdog timer that de-energises the coil
  even if the main loop stalls, crashes, or is killed. A 12V solenoid held on is
  a burnt coil.
* The arm switch is debounced and read as a hard interlock. Software never
  bypasses it.
"""
import atexit
import logging
import threading
import time

LOGGER = logging.getLogger(__name__)

HIGH = 1
LOW = 0


class MockGpioBackend:
    """In-memory GPIO for development. The arm switch can be toggled from the UI."""

    name = "mock"

    def __init__(self):
        self._levels = {}
        self._inputs = set()

    def setup_output(self, pin, initial):
        self._levels[pin] = initial

    def setup_input(self, pin, pull_up=True):
        self._inputs.add(pin)
        # Idle level of a pulled-up input with the switch open.
        self._levels.setdefault(pin, HIGH if pull_up else LOW)

    def read(self, pin):
        return self._levels.get(pin, HIGH)

    def write(self, pin, level):
        self._levels[pin] = level

    def cleanup(self):
        self._levels.clear()

    def set_input_level(self, pin, level):
        """Test/development hook: drive an input pin from software."""
        self._levels[pin] = level


class JetsonGpioBackend:
    """Real hardware, via the Jetson.GPIO library in BOARD pin numbering."""

    name = "jetson"

    def __init__(self):
        import Jetson.GPIO as GPIO  # noqa: N814

        self._gpio = GPIO
        GPIO.setmode(GPIO.BOARD)
        GPIO.setwarnings(False)

    def setup_output(self, pin, initial):
        self._gpio.setup(pin, self._gpio.OUT, initial=initial)

    def setup_input(self, pin, pull_up=True):
        pud = self._gpio.PUD_UP if pull_up else self._gpio.PUD_DOWN
        self._gpio.setup(pin, self._gpio.IN, pull_up_down=pud)

    def read(self, pin):
        return self._gpio.input(pin)

    def write(self, pin, level):
        self._gpio.output(pin, level)

    def cleanup(self):
        self._gpio.cleanup()


def build_backend(name="auto"):
    """Return a GPIO backend; ``auto`` prefers real hardware when available."""
    if name in ("auto", "jetson"):
        try:
            return JetsonGpioBackend()
        except Exception as error:  # ImportError on a workstation, RuntimeError off-Jetson
            if name == "jetson":
                raise
            LOGGER.warning("Jetson.GPIO unavailable (%s); using the mock backend.", error)
    return MockGpioBackend()


class ArmSwitch:
    """Debounced read of the illuminated toggle switch."""

    def __init__(self, backend, config):
        self._backend = backend
        self._pin = config.arm_switch_pin
        self._active_low = config.arm_switch_active_low
        self._debounce = config.debounce_seconds
        backend.setup_input(self._pin, pull_up=self._active_low)
        self._stable = self._raw()
        self._candidate = self._stable
        self._changed_at = time.monotonic()

    def _raw(self) -> bool:
        level = self._backend.read(self._pin)
        return level == (LOW if self._active_low else HIGH)

    def update(self) -> bool:
        """Sample the pin. Returns the debounced armed state."""
        reading = self._raw()
        now = time.monotonic()
        if reading != self._candidate:
            self._candidate = reading
            self._changed_at = now
        # Not elif: with debouncing disabled a change must land on this same call,
        # not wait for the next one.
        if reading != self._stable and (now - self._changed_at) >= self._debounce:
            self._stable = reading
            LOGGER.info("Arm switch -> %s", "ARMED" if reading else "SAFE")
        return self._stable

    @property
    def is_armed(self) -> bool:
        return self._stable


class SolenoidRelay:
    """The firing relay, with a watchdog that guarantees the coil turns back off."""

    def __init__(self, backend, config, max_pulse_seconds):
        self._backend = backend
        self._pin = config.relay_pin
        self._active_low = config.relay_active_low
        self._max_pulse = max_pulse_seconds
        self._lock = threading.Lock()
        self._watchdog = None
        self._energised_at = None

        backend.setup_output(self._pin, self._inactive_level)
        atexit.register(self.deenergise)

    @property
    def _active_level(self):
        return LOW if self._active_low else HIGH

    @property
    def _inactive_level(self):
        return HIGH if self._active_low else LOW

    @property
    def is_energised(self) -> bool:
        return self._energised_at is not None

    def pulse(self, seconds: float) -> float:
        """Energise the coil for ``seconds``, clamped by the watchdog ceiling."""
        duration = max(0.0, min(seconds, self._max_pulse))
        with self._lock:
            if self._watchdog is not None:
                self._watchdog.cancel()
            self._backend.write(self._pin, self._active_level)
            self._energised_at = time.monotonic()
            self._watchdog = threading.Timer(duration, self.deenergise)
            self._watchdog.daemon = True
            self._watchdog.start()
        LOGGER.info("Relay energised for %.0f ms", duration * 1000)
        return duration

    def deenergise(self) -> None:
        with self._lock:
            if self._watchdog is not None:
                self._watchdog.cancel()
                self._watchdog = None
            self._backend.write(self._pin, self._inactive_level)
            self._energised_at = None

    def update(self) -> None:
        """Belt-and-braces de-energise from the main loop, independent of the timer."""
        started = self._energised_at
        if started is not None and (time.monotonic() - started) >= self._max_pulse:
            LOGGER.warning("Relay watchdog tripped from the main loop.")
            self.deenergise()

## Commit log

2026-09-01 Initial commit of cook_vision project
    Vision, HUD, and firing-interlock pipeline for a Jetson Nano-driven
    pneumatic Nerf launcher targeting the University of Michigan Block M.
    [enclosure.scad]
2026-09-01 Fix arm-switch pull-up value in wiring.md: 1kΩ, not 10kΩ
    The recovered copy of this file (restored from a stale sync to the
    Nano after local data loss) still had the earlier, insufficient 10kΩ
    value. Pin 16 has an internal pull-down baked into the pinmux that
    Jetson.GPIO can't disable, strong enough that 10kΩ only reached ~1V
    open-circuit; 1kΩ is what was actually verified on hardware to
    overpower it.
2026-09-01 Add parts list with sourcing links
    Reconciles the original Obsidian planning note's Amazon/RobotShop
    links with the part numbers and specs docs/wiring.md has since
    confirmed against the physical hardware.
2026-09-01 Document fuse holder assembly and color code in wiring.md
    Notes that cheap inline fuse holders ship as a single wire loop that
    needs cutting to form the two leads, plus the ATO/ATC/Mini blade-fuse
    color code for the 1-2A rating this build calls for.
2026-09-02 Add fire sound effect, defaulting output to the Nano's HDMI audio
    Plays a clip per shot on a daemon thread via mpg123/ffplay/cvlc/aplay,
    never touching the frame budget. Defaults the ALSA device to
    plughw:0,3 (HDMI) since burninator's display speakers are the intended
    output, not the unplugged analog jack -- confirmed on hardware that
    the HDMI jack-sense only latches if the display is already on when the
    Nano boots.
    [app.py, config.py, sound.py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]
2026-09-06 Redesign enclosure as two-part telescoping box, add rear shell STL
    Front shell carries the display/switch/camera face; rear shell holds
    the Nano/battery/protoboard bays and CO2 hopper. No fasteners — the
    halves telescope together and lock with a printed snap bump. Rear
    shell STL rendered and exported from OpenSCAD for a fit check.
    [enclosure.scad, rear_shell.stl]
2026-09-06 Add front shell STL, flip render flag to match
    Front shell exported and verified watertight/manifold, same footprint
    as the rear shell (243.9x170mm) with expected 46mm collar depth.
    [enclosure.scad, front_shell.stl]
2026-09-07 Redesign enclosure v3: single-depth box + slide-in back panel
    Replaces the telescoping two-shell design with one constant-depth box
    (front face + all four walls, open at the back) and a thin panel that
    slides into channel grooves cut into the box's own side walls. The
    CO2 hopper moves from the back to the right side wall. Nano/battery/
    protoboard now mount to the removable panel instead of the box, and
    the Nano's mounting-hole positions and dimensions are measured
    directly from NVIDIA's B01 STEP file rather than a generic
    placeholder. STLs re-exported and verified watertight for both parts.
    [enclosure.scad, front_shell.stl, rear_shell.stl]
2026-09-07 Fix back panel print orientation
    The panel's flat face sat at max Z with standoffs reaching toward
    min Z — backwards from what a slicer assumes on import (native Z-up
    = flat face down, bed-ready). A naive import would have rested the
    part on the standoff tips instead. Added a print-time-only flip
    (rotate 180° about X, translate back near the origin) to the
    standalone panel export; the fit geometry used by render_assembly is
    untouched. Re-exported rear_shell.stl, verified Z now runs 0 to 27.4
    (flat face at the bottom) and is still watertight.
    [enclosure.scad, rear_shell.stl]
2026-09-07 Shrink enclosure footprint 25.6% to fit a 220mm print bed
    A friend's printer flagged the previous 261.3x170mm footprint as
    roughly a quarter too big. Tightened side_margin and component_margin,
    moved the switch off the display's row and next to the camera, shrunk
    the cable pass-through to a single 12mm hole, and mounted the Nano
    rotated 90 degrees (same trick already used for the battery) so its
    narrower 79mm side sets the column width instead of 100mm, trading
    width for the back panel's spare height. box_w and box_h are now each
    explicitly the larger of the front-face requirement and the back
    panel's electronics requirement, since tightening broke the coincidence
    that let one side always dr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
    [enclosure.scad, front_shell.stl, rear_shell.stl]
2026-10-19 Shrink enclosure for faster/safer printing, drop protoboard
    total_depth 101.6mm -> 90mm (verified wiring_margin/hopper clearance
    still hold via OpenSCAD echo, not hand arithmetic) and box_h
    173.8mm -> 150mm, first by dropping the protoboard (wired inline
    instead of on a dedicated board, per Jeff) which eliminated it as a
    mount/vent target, then by trimming the camera/switch row's margins
    down to what the hardware actually needs. box_w stays at 176.9mm,
    still pinned by the display and a near-tie with electronics_w.
    Verified every change with real OpenSCAD 2021.01 renders (Simple:
    yes, no warnings) rather than the file's prior "reasoned, not
    rendered" numbers -- several stale comments (compon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
2026-11-06 Match firing defaults to the transistor-driven relay; let f fire without a target
    The relay is now driven through a 2N2222 that pulls IN low with the board
    jumpered to L, so pin HIGH means fire: relay_active_low defaults to False.
    The manual trigger (f) now skips the target gates (lock, confidence, bore)
    but still honours every safety gate: startup lockout, arm switch, software
    safety, cooldown and relay idle. Tests cover both halves.
    lock_frames lowered from 8 to 6 for a faster lock.
2026-11-06 Point sync-to-jetson.sh at the Nano's new address
